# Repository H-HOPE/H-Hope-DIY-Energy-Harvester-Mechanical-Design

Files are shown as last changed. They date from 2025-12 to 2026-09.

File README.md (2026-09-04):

<div align="right">
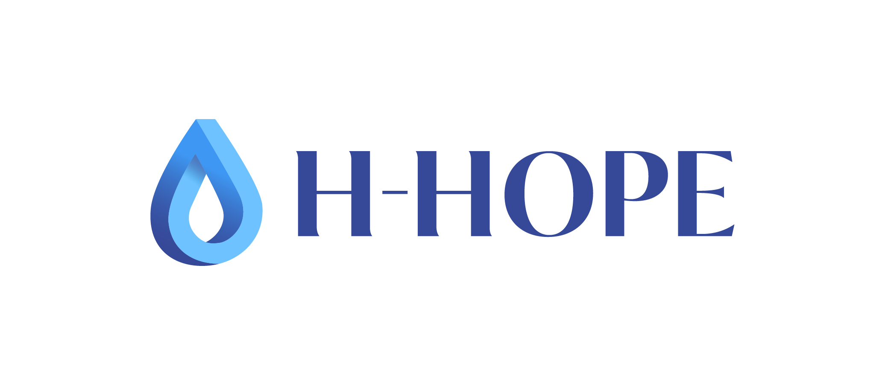
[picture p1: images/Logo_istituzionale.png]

</div>

# H-HOPE DIY Energy Harvester

**This guide is Part I of a three-part H-HOPE DIY build series.** Part I shows how to build the mechanical H-HOPE DIY energy harvester (the ‘harvester’) (the frame, oscillating cylinder, springs, transmission, flywheel and mechanical coupling) as either a **standalone demonstrator** or as a **complete mechanical module ready to connect to the H-HOPE DIY generator**. It contains everything a builder, student, or maker needs to go from parts to a working mechanical harvester:

---

**[Part II - H-HOPE DIY Generator](https://github.com/H-HOPE/H-HOPE-H-Hope-energy-harvester-induction-generator-design)** - Instructions for building the H-HOPE DIY generator that converts the harvester’s rotary/mechanical output into electrical power

**[Part III - H-HOPE DIY Electronics](https://github.com/H-HOPE/H-Hope-energy-harvester-electronic-design)** - Power control electronics that convert the H-HOPE DIY generator’s AC output into a USB-compatible DC supply for charging phones and small devices.

---

## Table of Contents

- [Introduction and principle of operation](#introduction-and-principle-of-operation)
- [Materials & Tools](#materials--tools)
  - [Bill of Materials & Price Estimate](#bill-of-materials--price-estimate)
  - [Tools](#tools)
- [3D Printed Parts for the harvester](#3d-printed-parts-for-the-harvester)
- [Harvester Assembly](#harvester-assembly)
  - [Aluminium frame and preloading mechanism (D and C)](#aluminium-frame-and-preloading-mechanism-d-and-c)
  - [Cylinder assembly (A)](#cylinder-assembly-a)
  - [Flywheel assembly (G)](#flywheel-assembly-g)
  - [Spring and rod assembly (B, E)](#spring-and-rod-assembly-b-e)
  - [Shaft (I)](#shaft-i)
    - [Shaft assembly With DIY Generator](#shaft-assembly-with-diy-generator)
    - [Without DIY Generator](#without-diy-generator)
  - [Assembly of the cylinder, springs and vertical rod to the Harvester frame](#assembly-of-the-cylinder-springs-and-vertical-rod-to-the-harvester-frame)
  - [Test of the operation](#test-of-the-operation)
- [Water-channel measurement results](#water-channel-measurement-results)
  - [Measurement parameters](#measurement-parameters)
    - [Cylinder size](#cylinder-size)
    - [Water velocity](#water-velocity)
    - [Oscillation amplitude](#oscillation-amplitude)
  - [Measurements results](#measurements-results)
    - [Best-performing configuration](#best-performing-configuration)
    - [Cylinder size comparison](#cylinder-size-comparison)
    - [Effect of water velocity](#effect-of-water-velocity)
  - [Practical build recommendation](#practical-build-recommendation)

---

## Introduction and principle of operation

The **harvester**, visible in Figure 1 is a simple, modular, and accessible mechanical system to convert the kinetic energy of flowing water into rotational motion, which is then converted into electrical power through a generator.  

The design is primarily aimed at **hobbyists, students, and researchers**, using standard aluminium profiles, off-the-shelf mechanical components, and basic workshop tools. All plastic components can be easily 3D-printed, with their models included in this build guide, while all remaining harvester parts are available on AliExpress for convenient sourcing.
The design emphasizes ease of assembly, allowing users to construct a fully functional water energy harvesting system without specialized machinery. By following step-by-step assembly instructions and using off-the-shelf parts, anyone can replicate the harvester to generate electricity from flowing water such as a small stream, river, channel, making it a practical and educational DIY project for sustainable energy exploration. For optimal performance, a water velocity between 0.6 and 1.0 m/s is recommended.

<p align="center">
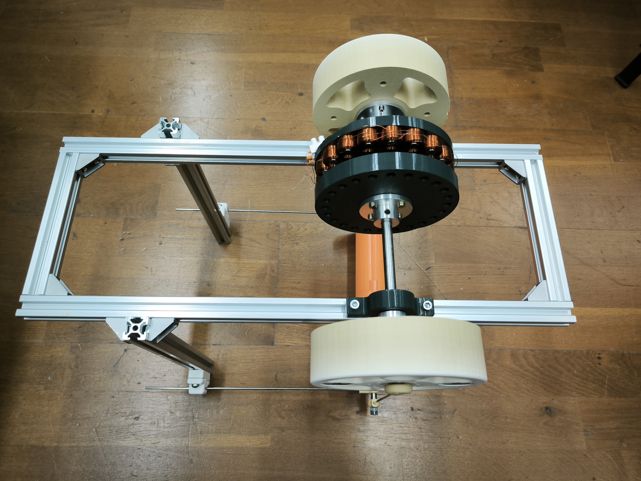
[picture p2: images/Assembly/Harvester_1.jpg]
  
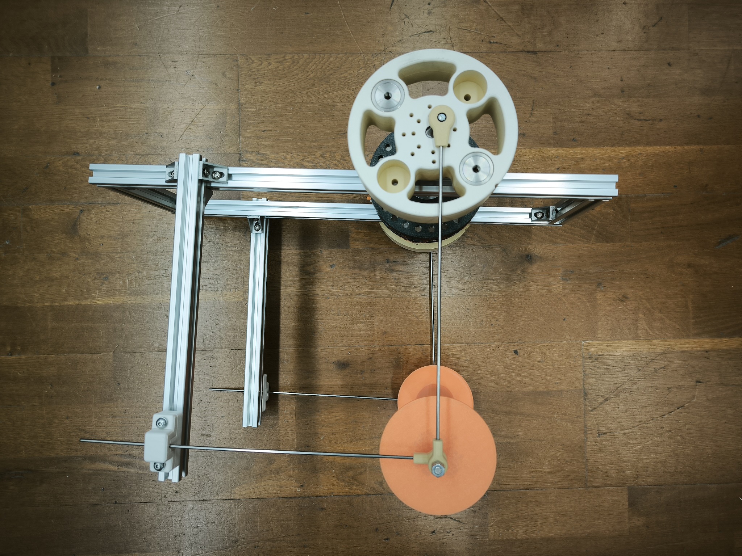
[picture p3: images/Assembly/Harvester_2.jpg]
  
</p>
<p align="center">
<b>Fig. 1:</b> Assembled harvester.</p>

<p align="center">
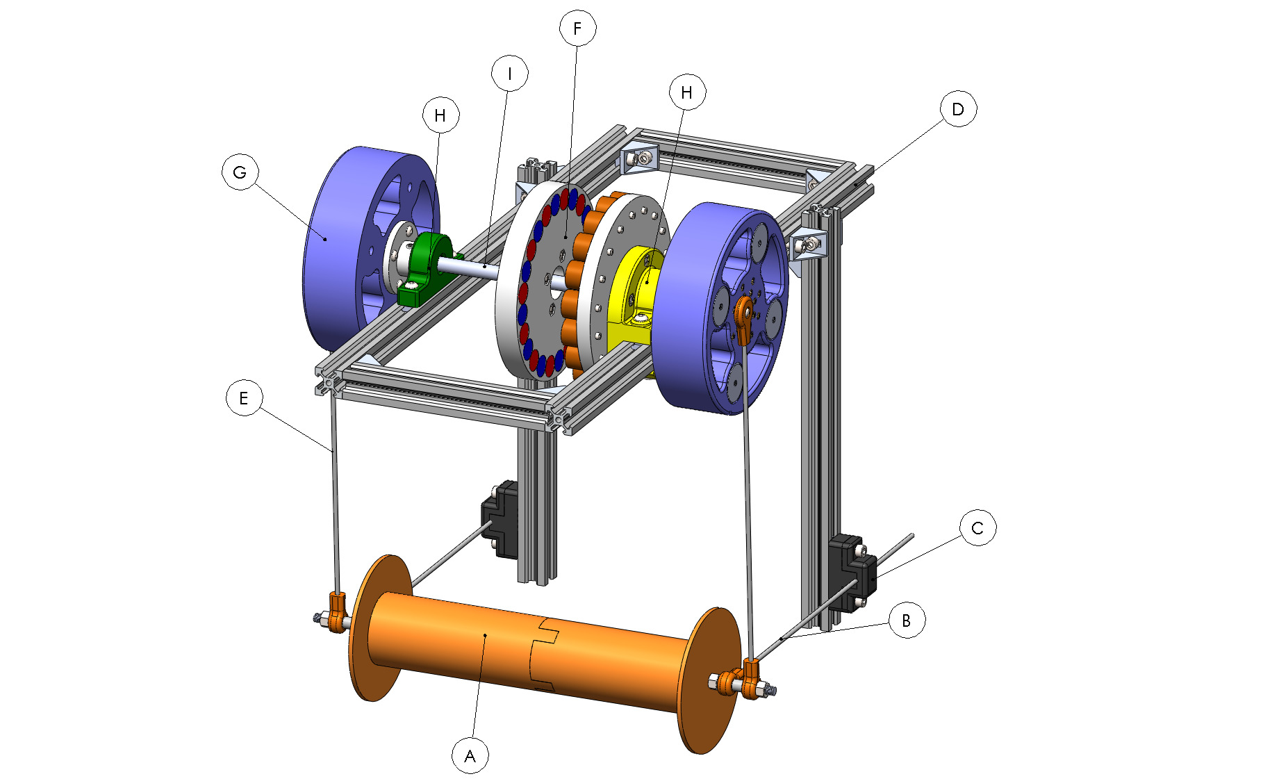
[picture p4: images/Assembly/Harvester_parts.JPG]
H-HOPE harvester
  
</p>

<p align="center"><b>Fig. 2:</b> View of the harvester model.</p>

The model of the harvester, visible in Figure 2 shows the mechanical structure of the harvester. The assembly consists of a modular aluminium frame supporting a horizontal oscillating cylinder, a flywheel, and vertical guide elements to transmit motion to a central shaft. In this configuration, the **cylinder (A)** is mounted horizontally and attached via **return springs (B)** to allow vertical oscillations while constraining horizontal movement. **Preloading mechanisms (C)** can adjust the spring tension to set the cylinder’s equilibrium position depending on its weight. **Vertical connecting rods (E)** with bearings transfer the oscillating motion of the cylinder to a **shaft (I)**,  which is supported by **bearings (H)**. This shaft is coupled to a **rotor (F)** and **flywheel (G)**, which help smooth the motion and can be linked to an induction generator. The **aluminium frame (D)** provides a modular and rigid support structure for the entire system. The pulley and cable arrangement visible in the image ensures the vertical movement of the cylinder is mechanically transmitted to the rotating shaft, which can then drive a generator rotor.

**Principle of Operation - Vortex-Induced Vibration (VIV)**

The vortex shedding process results in quasi-periodic pressure fluctuations around the cylinder. These alternating pressure differentials between the upper and lower surfaces generate an unsteady lift force, acting primarily in the transverse (vertical) direction. When the cylinder is mounted to permit vertical motion while restricting horizontal displacement, this oscillatory lift force induces vertical vibrations of the structure. The magnitude of the lift force is important for both performance and design of the VIV energy harvesters. For a given pressure differential, the lift force is proportional to the surface area exposed to the flow. Thus, increasing the cylinder diameter increases the area subject to pressure fluctuations, resulting in a higher lift force during vortex shedding. Where channel or stream dimensions allow, employing a cylinder with the maximum feasible height is advantageous, as it increases oscillation amplitude and improves the energy extraction potential and overall efficiency of the harvester.

Vertical harvester motion forms the basis for energy extraction in systems designed to harness vortex-induced vibrations (VIV), where mechanical oscillation energy is converted into usable electrical power. When the vortex shedding frequency approaches the natural frequency of the structure, resonance may occur, producing large-amplitude oscillations. Devices designed to extract energy from these oscillations are referred to as VIV energy harvesters, such as the system developed here. The harvester’s operating principle is based on Kármán vortex shedding coupled with large-amplitude oscillations of the energy harvester.

To harvest the lift force generated by the oscillating flow, the structure must allow large oscillatory displacements that can be sustained over time. Consequently, the natural (resonant) frequency of the harvester should be tuned to match, or lie very close to, the dominant vortex-shedding frequency of the flow, thereby maximising the energy captured per cycle.

---

## Materials & Tools

All the parts can be sourced from [AliExpress](https://www.aliexpress.com) using the links below. Some items (e.g., profiles or nuts) may also be available locally for faster delivery. Below is a complete list of all the components and hardware required for the build, including direct links and backup snapshots to AliExpress.

### Bill of Materials & Price Estimate

#### Frame
- 2x Bosch profile 500 mm ↘︎
- 2x Bosch profile 150 mm → [AliExpress items](https://www.aliexpress.com/item/1005002652962344.html) [Page screenshot](./images/1_profiles.PNG)
- 2x Bosch profile 300 mm ↗
- 20× Corner Bracket – joins → [AliExpress item](https://www.aliexpress.com/item/1005008248063572.html) [Page screenshot](./images/2_brackets.PNG)

#### Bearings
- 2× 10×26×8 mm (6000 OPEN) → [AliExpress item](https://www.aliexpress.com/item/1000006697893.html) [Page screenshot](./images/3_bearings_big.PNG)
  *(Open type has slightly less friction than closed)*  
- 2× 3×10×4 mm → [AliExpress item](https://www.aliexpress.com/item/1005007624995531.html) [Page screenshot](./images/3_bearings_small.PNG)

#### Flange
- 2× 10 mm inner diameter → [AliExpress item](https://www.aliexpress.com/item/1005006166768847.html) [Page screenshot](./images/4_flange.PNG)

#### Weights
- 4× (8×) 100 g weights → [AliExpress item](https://www.aliexpress.com/item/1005009254304005.html) [Page screenshot](./images/5_weights.PNG)

#### Inserts
- 50× M3 inserts (OD 4.5 mm, length 8 mm) → [AliExpress item](https://www.aliexpress.com/item/1005009169647177.html) [Page screenshot](./images/6_inserts.PNG)

#### Threaded Rod
- 1× M6, 500 mm → [AliExpress item](https://www.aliexpress.com/item/1005010030305641.html) [Page screenshot](./images/7_threaded_rod.PNG)

#### Shaft
- 1× 300 mm, Ø10 mm rod → [AliExpress item](https://www.aliexpress.com/item/1005007648254828.html) [Page screenshot](./images/12_main_rod.PNG)

#### Spacers
- 10× OD8 × M6 spacers, length 8 mm → [AliExpress item](https://www.aliexpress.com/item/1005009939446609.html) [Page screenshot](./images/8_spacer.PNG)

#### Stainless Steel Round Rod
- 4× 300 mm, Ø3 mm rods → [AliExpress item](https://www.aliexpress.com/item/1005006331386855.html) [Page screenshot](./images/9_round_rod.PNG)

#### Bolts, Nuts & Washers
- 10pcs M3 bolts, 12 mm in lenght → [AliExpress item](https://www.aliexpress.com/item/4001072025844.html) [Page screenshot](./images/10__M3_screws.PNG)

- 6pcs M6 nuts → [AliExpress item](https://www.aliexpress.com/item/1005006982532067.html) [Page screenshot](./images/11_M6_nuts.PNG)

- 4PCS M5 nuts and bolts 25 mm in lenght (for mounting the generator)
  
**Total Estimated Cost for the material (2025)** *(Generator and electronics not included)*

**≈ 95 €**

---

### Tools
- Screwdrivers, wrenches
- Drill/driver, bench vise
- Metal saw
- Vice
- 3D printer
- Safety gear (gloves, goggles)
- Quick glue
- Soldering iron (for inserting inserts)

---
## 3D Printed Parts for the harvester

A total of 17 parts need to be 3D-printed to complete the harvester assembly. All parts are available in both STL and STEP formats and can be downloaded here: [3D printed harvester parts](./3D%20parts). For added protection against moisture or water exposure, you can optionally coat the printed parts with a plastic spray sealant. The printing process of the parts is visible in Figure 3.

<p align="center">
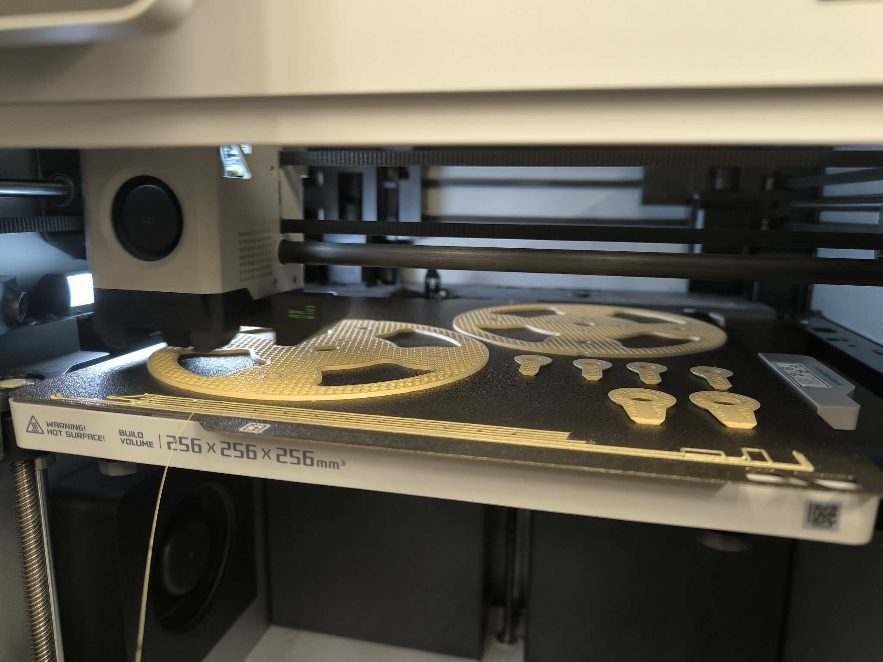
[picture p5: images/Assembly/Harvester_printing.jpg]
H-HOPE harvester
  
</p>

<p align="center"><b>Fig. 3:</b> Printing the 3D parts for the harvester.</p>

---

## Harvester Assembly

 - The **harvester** may be assembled either **with the H-HOPE DIY generator** attached, as visible in Figure 4 left **or as a standalone mechanical module**, as visible in Figure 4 right. When built without the generator the unit can function as a mechanical demonstrator and can be left ready for later coupling to a third-party generator.

 - Build instructions and parts lists for both configurations (Mechanical only and Mechanical and Generator) are provided below so the builder can choose the configuration that best fits their goals.

<p align="center">
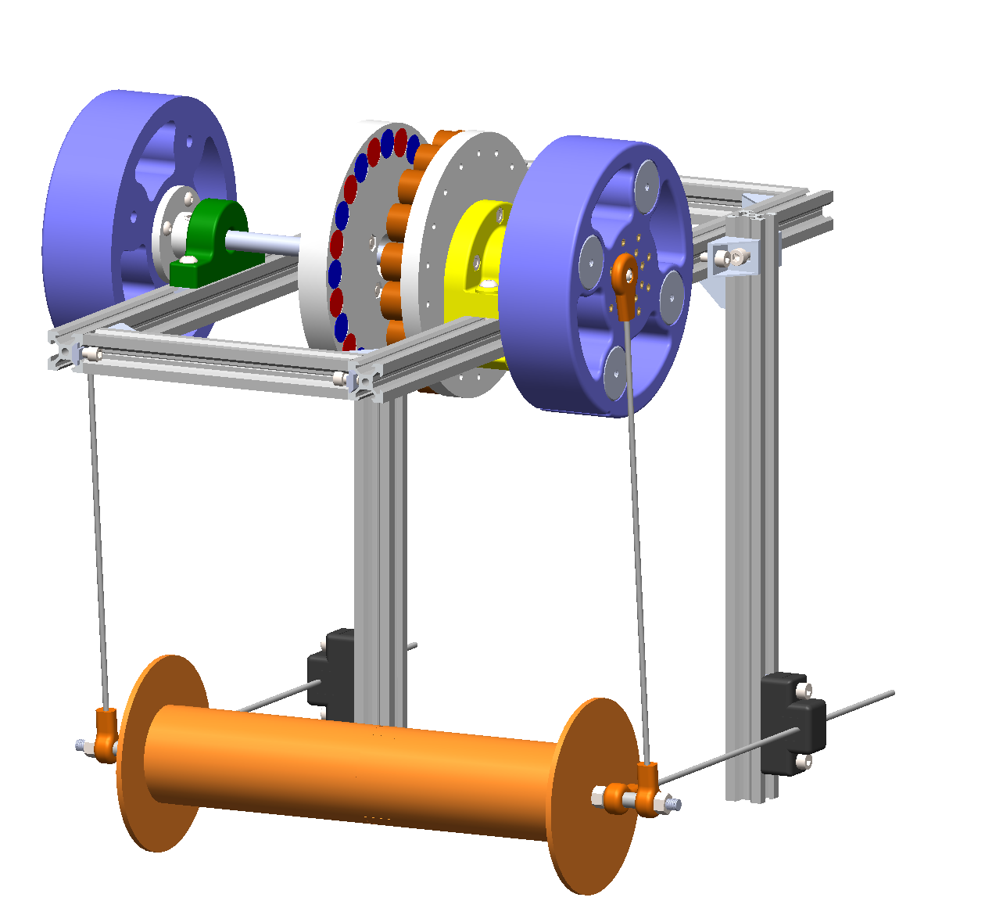
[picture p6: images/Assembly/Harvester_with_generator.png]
  
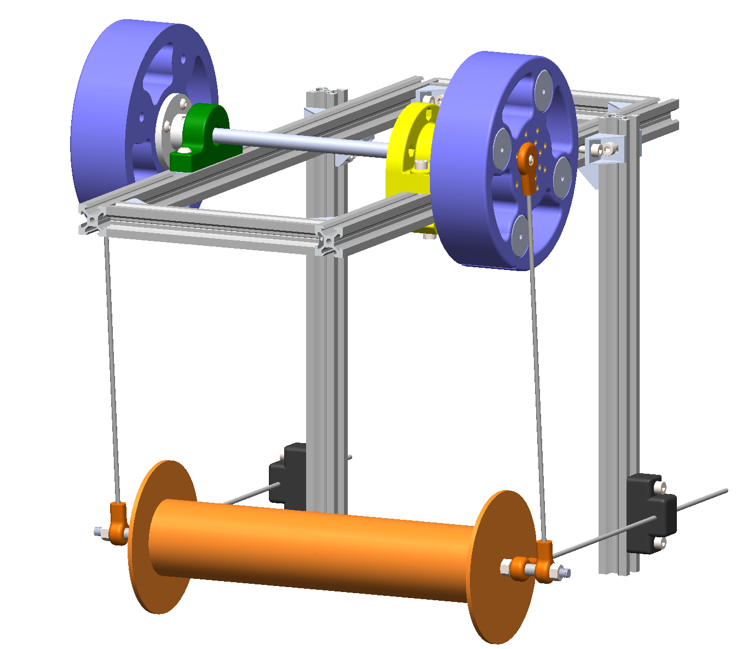
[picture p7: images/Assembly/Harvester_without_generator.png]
  
</p>
<p align="center">
<b>Fig. 4:</b>Harvester assembly with (left) and without (right) the H-HOPE DIY generator.
</p>

Figure 4 shows a model view of the harvester, with (left) and without (right) the H-HOPE DIY generator, displaying its individual mechanical components and how they are assembled.

The assembly process, regardless of the generator installation, is identical up to the "Shaft" section. This section is divided into two parts, allowing the user to follow the procedure either with or without the generator assembly.

### Aluminium frame and preloading mechanism (D and C)

The assembly of the harvester begins with the assembly of the aluminium frame (D) and preloading mechanism (C).

<p align="center">
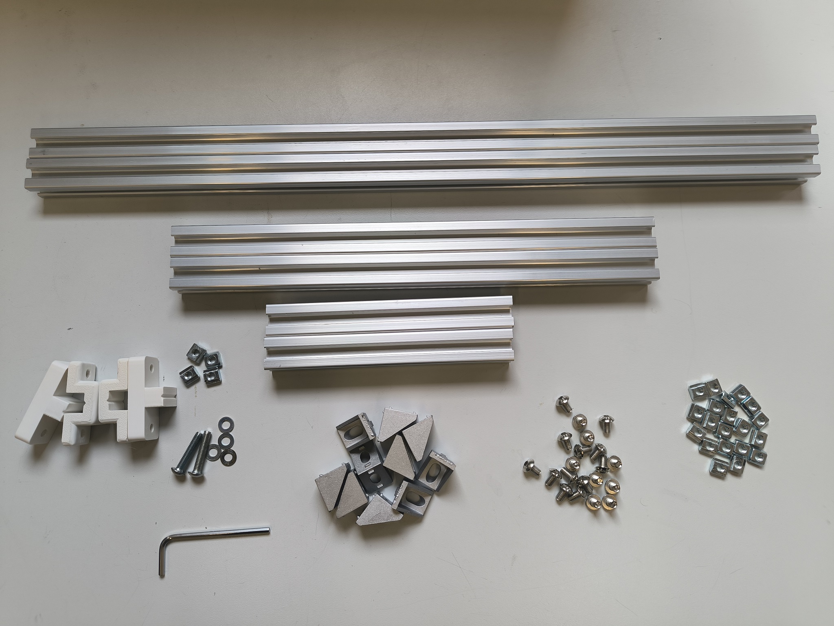
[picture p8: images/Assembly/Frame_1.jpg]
  
</p>
<p align="center">
<b>Fig. 5:</b> Harvester frame and preloading mechanism assembly parts.
</p>

First assemble the **horizontal part of the aluminium frame (D)** with corner brackets and M6 fasteners. Place two 500 mm, 20x20 mm Aluminium profiles in parallel. Add two 150 mm profiles at each end, to connect the 500mm profiles together. Assemble the profiles together with joints at each of the 4 corners, as visible in the animation on the right side of Figure 6. The finished harvester horizontal profile is visible in Figure 7.

<p align="center">
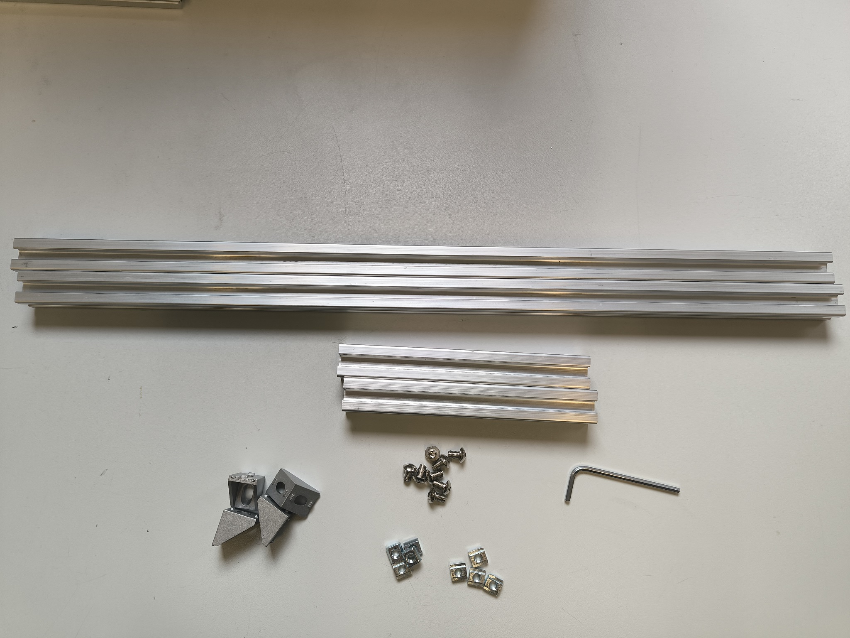
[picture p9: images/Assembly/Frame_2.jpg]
  
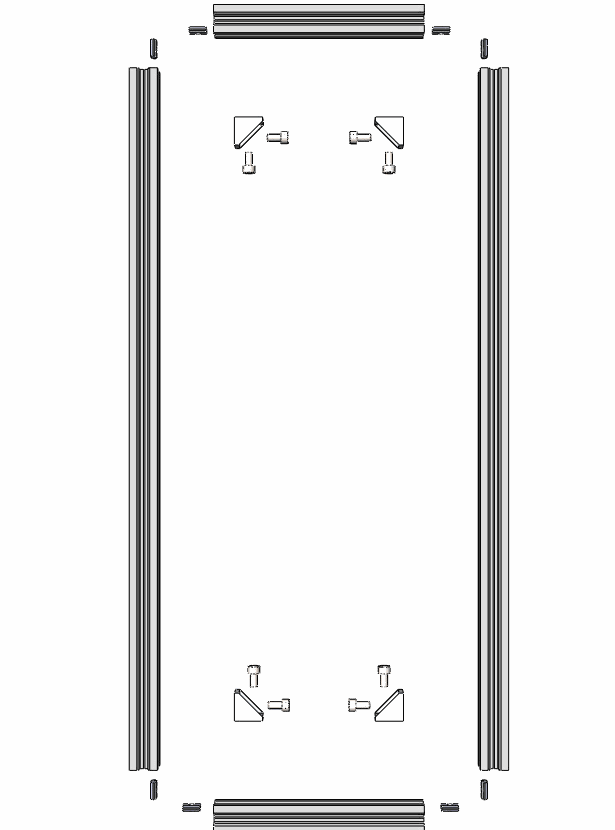
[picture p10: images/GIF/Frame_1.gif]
  
</p>
<p align="center">
<b>Fig. 6:</b> Harvester horizontal frame assembly parts (left) and animation of harvester horizontal frame assembly (right).
</p>

<p align="center">
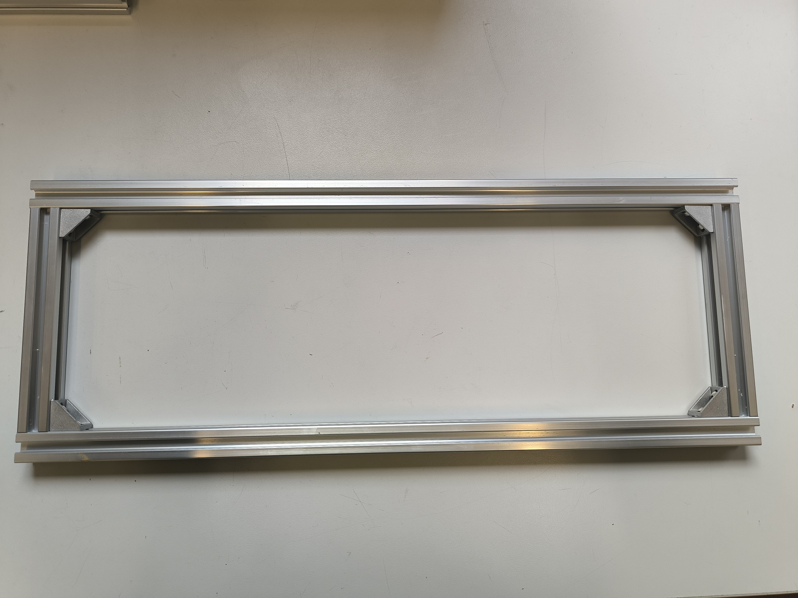
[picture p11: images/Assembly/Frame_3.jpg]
  
</p>
<p align="center">
<b>Fig. 7:</b> Completed harvester horizontal frame assembly.
</p>

**Assembly of the harvester vertical aluminium frame and preloading mechanism**.

First, install the preloading mechanism components (shown in Figure 8 and in the animation in Figure 9) onto the vertical 300 mm, 20x20 mm aluminium profiles. The required length of the four M5 bolts is 23 mm, however, in this assembly, 25 mm bolts were used along with two additional washers to achieve the correct overall length.

<p align="center">
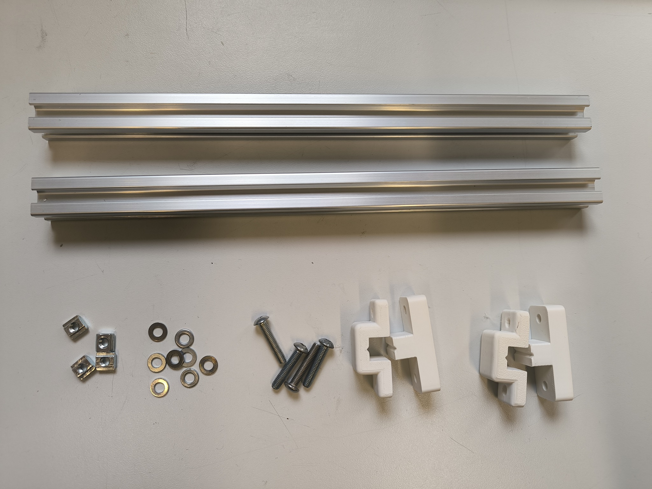
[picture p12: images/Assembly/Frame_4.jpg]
  
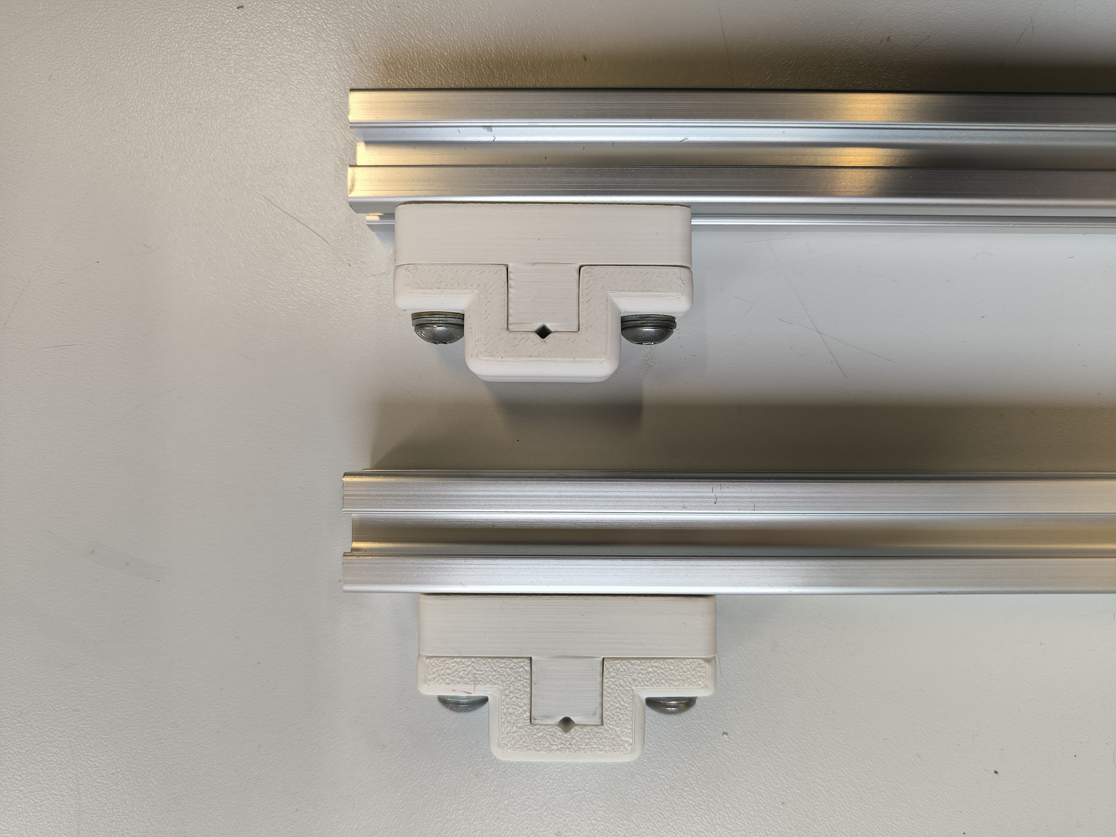
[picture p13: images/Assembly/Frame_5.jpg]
  
</p>
<p align="center">
<b>Fig. 8:</b> Harvester preloading mechanism parts (left) and finished assembly of the preloading mechanism (right).
</p>

<p align="center">
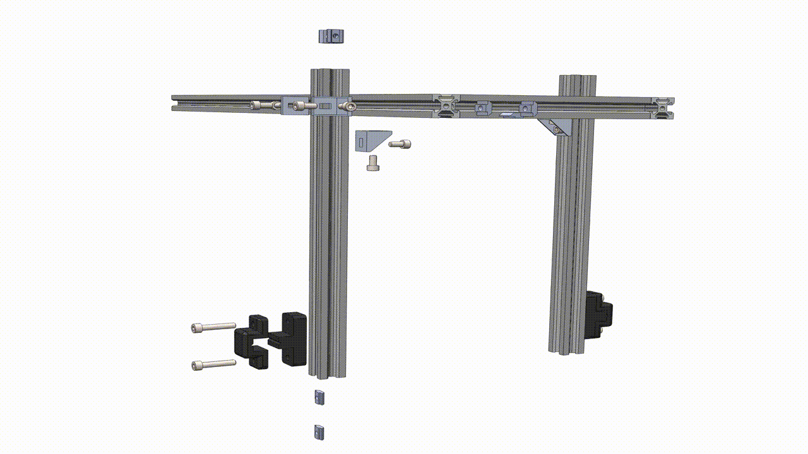
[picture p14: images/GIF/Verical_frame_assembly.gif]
  
</p>
<p align="center">
<b>Fig. 9:</b> Animation of harvester horizontal frame and preloading mechanism assembly.
</p>

Place each 300 mm profile vertically and secure it with three joints to the harvester horizontal profile, one at the bottom, one on the left side, and one on the right side, then repeat the same process on the opposite side of the frame, ensure that each profile extends 8 mm above the top of the frame and that the bottom part of the preloading mechanism is positioned 15 mm from the lower end of the vertical profile, as illustrated in the left side of the Figure 11. Ensure **profile alignment** to minimize bearing wear and losses.

Before connecting vertical profiles to the horizontal aluminium frame, sand off the excessive aluminium pins (if they exist) in corner joints to make a good connection, as visible in Figure 10 (left and right).

<p align="center">
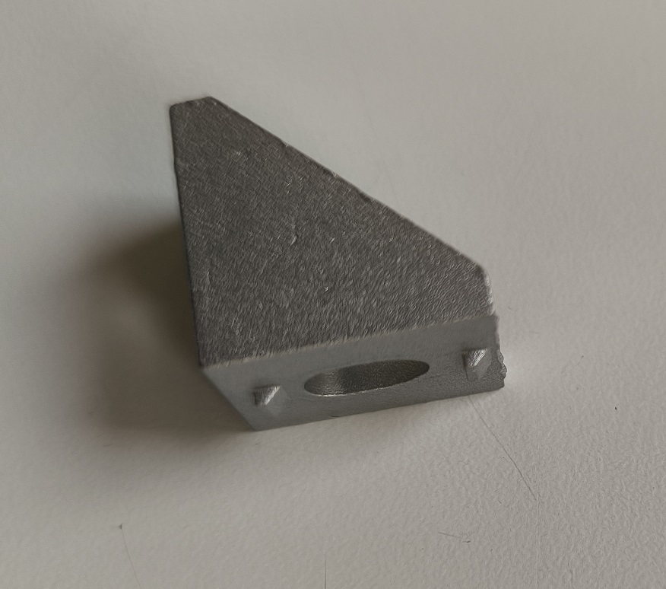
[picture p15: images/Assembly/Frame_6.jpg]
  
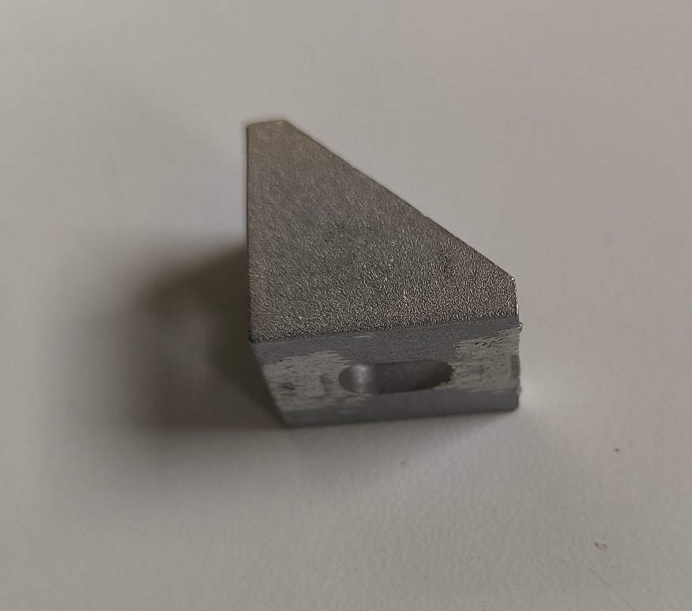
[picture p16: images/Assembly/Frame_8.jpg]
  
</p>
<p align="center">
<b>Fig. 10:</b> Sanded pins on aluminium joints.
</p>

<p align="center">
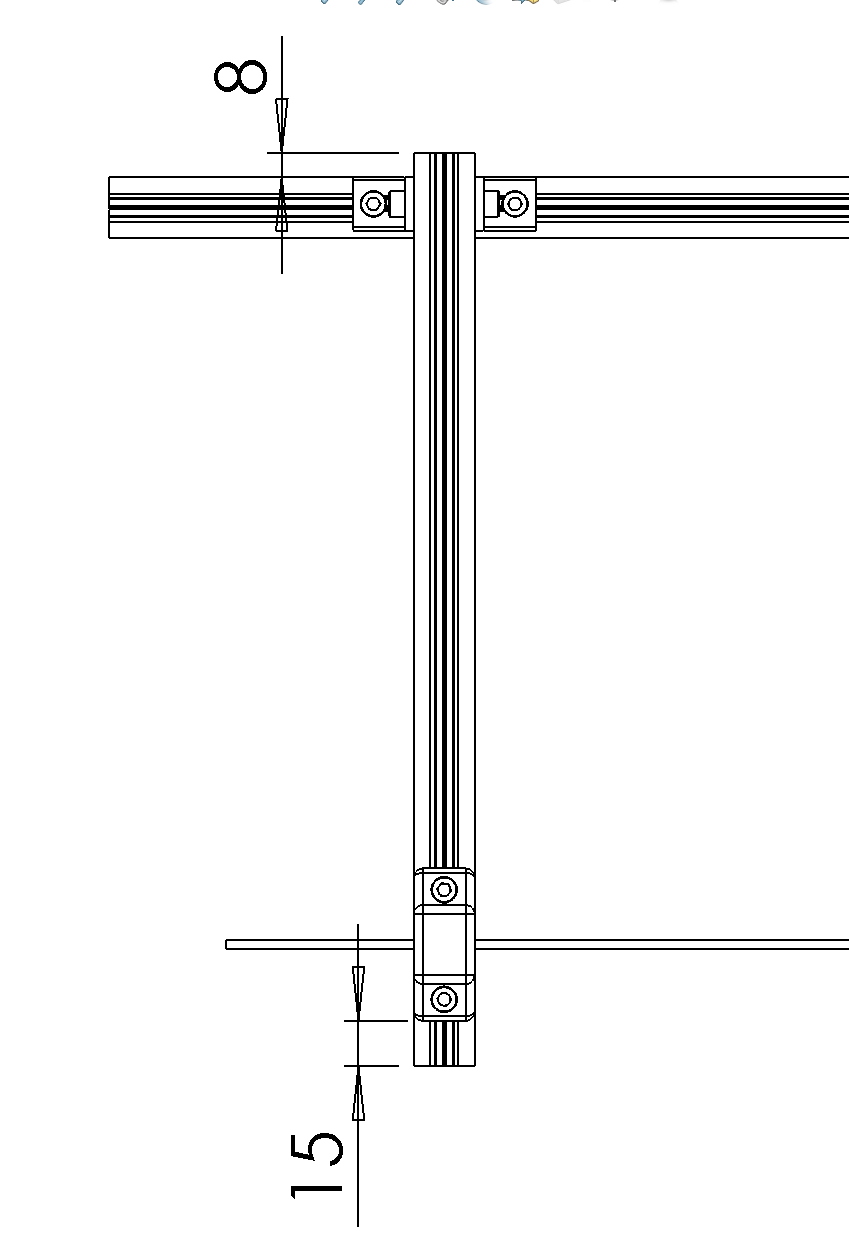
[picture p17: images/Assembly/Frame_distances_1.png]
  
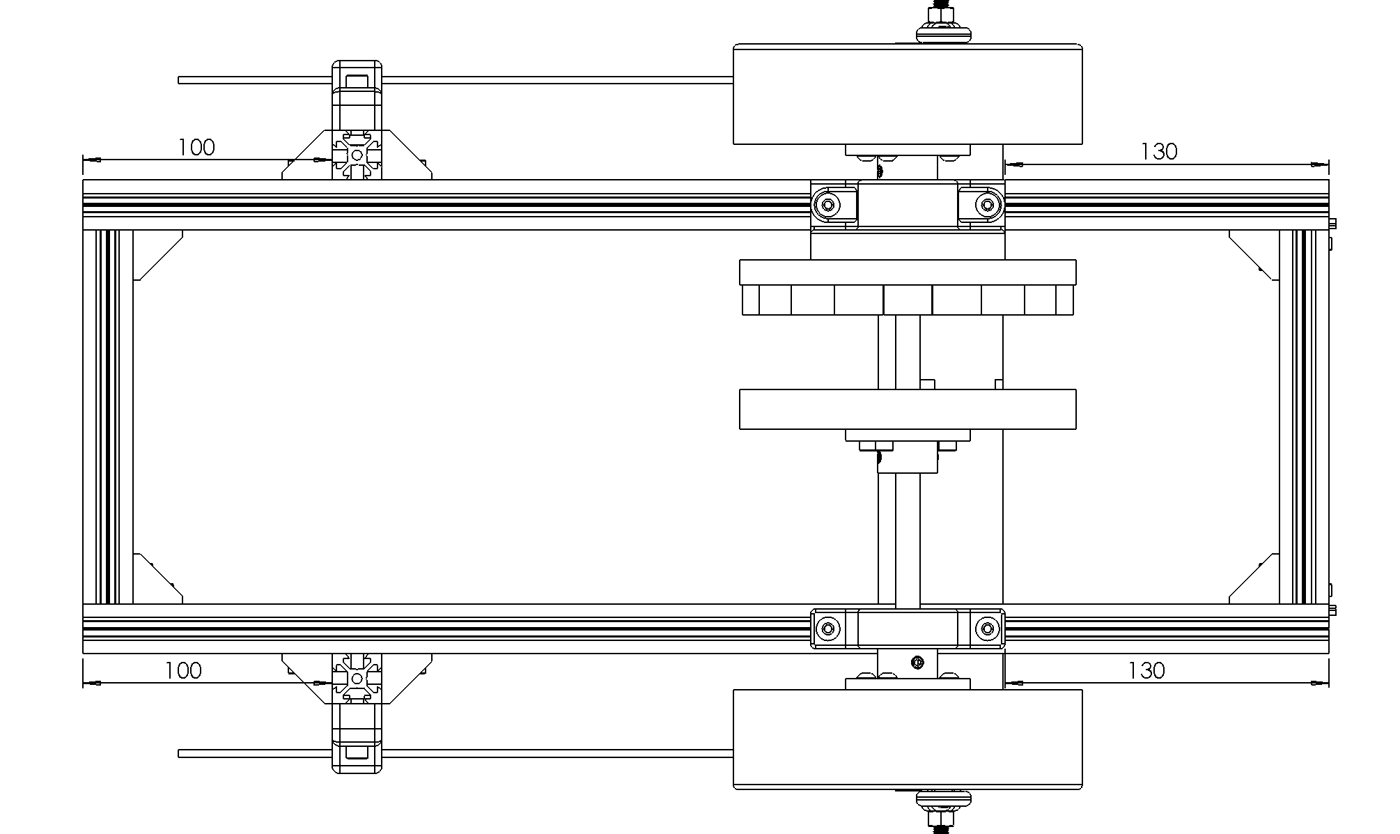
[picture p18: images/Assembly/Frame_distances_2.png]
  
</p>
<p align="center">
<b>Fig. 11:</b> Mounting offset of the preloading mechanism, vertical profiles (left) and offset of the items installed on the horizontal frame (right).
</p>

The finished frame assembly is shown in Figure 12.

<p align="center">
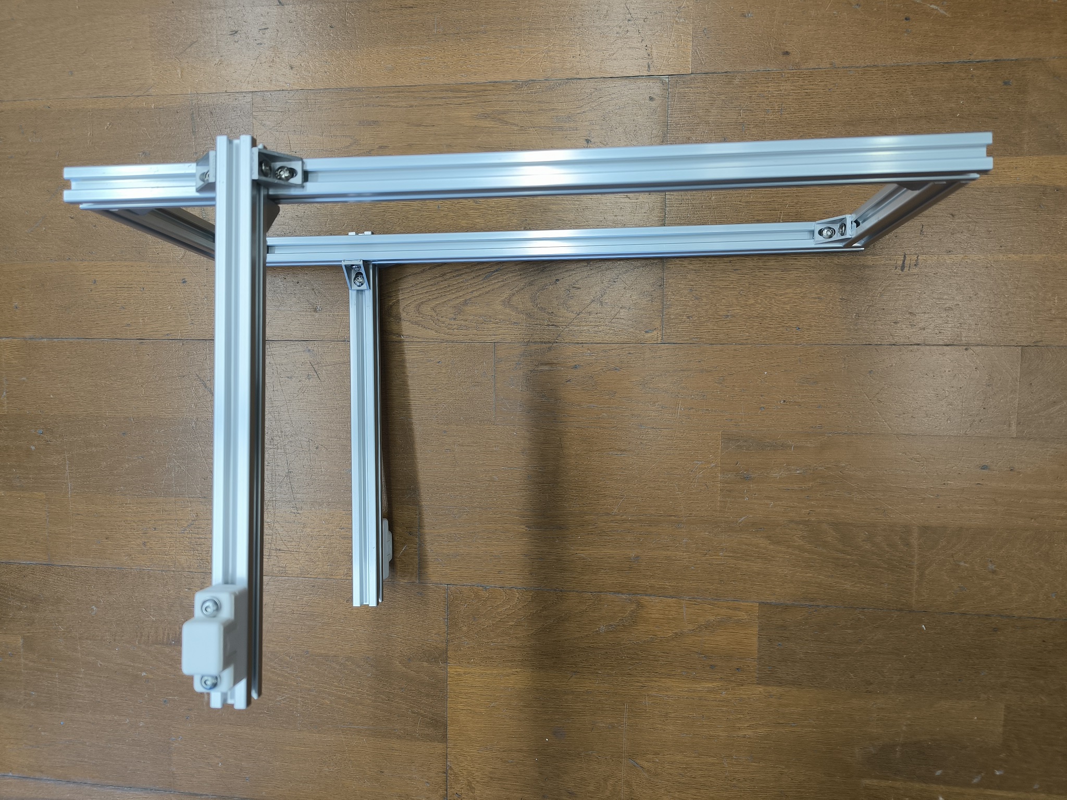
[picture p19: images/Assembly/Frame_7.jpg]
  
</p>

<p align="center"><b>Fig. 12:</b> Assembled harvester aluminium frame.</p>

---

### Cylinder assembly (A)

We continue with the harvester cylinder assembly (A).

In the left side of Figure 13 we can see the parts needed to assemble the harvester cylinder. We can see that the cylinder is 3D printed and is made from two parts. At each end of the cylinder there is a larger disc, that improves the harvester efficiency. The cylinder has a 6 mm hole running through its entire length. On the right side, there are six M6 nuts and two 6x8 mm spacers, below is a 500 mm M6 threaded rod.

<p align="center">
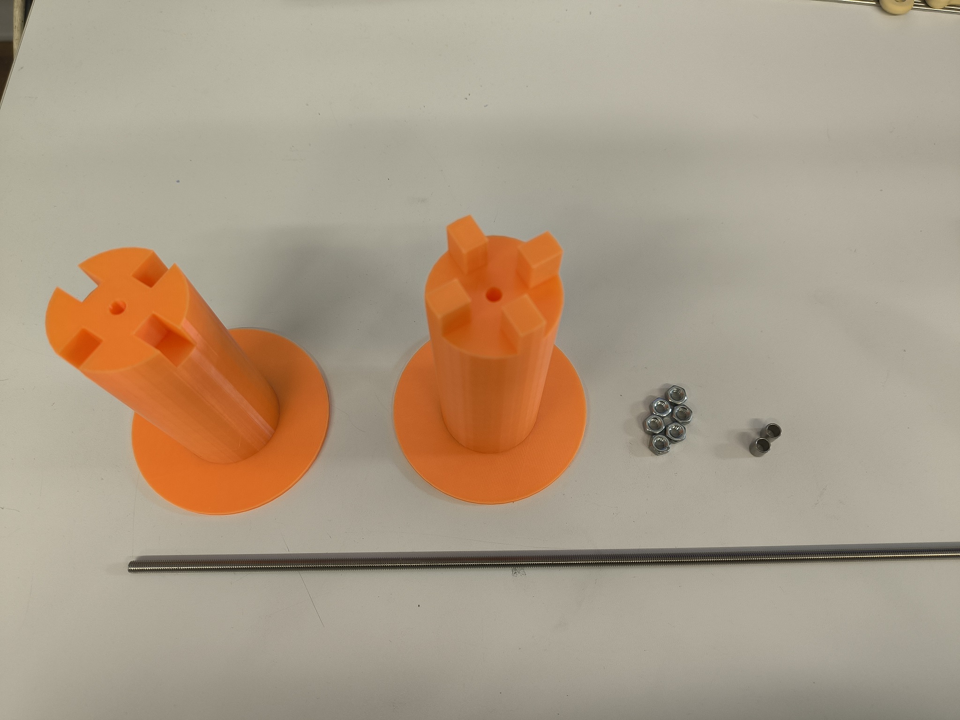
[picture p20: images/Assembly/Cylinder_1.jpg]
  
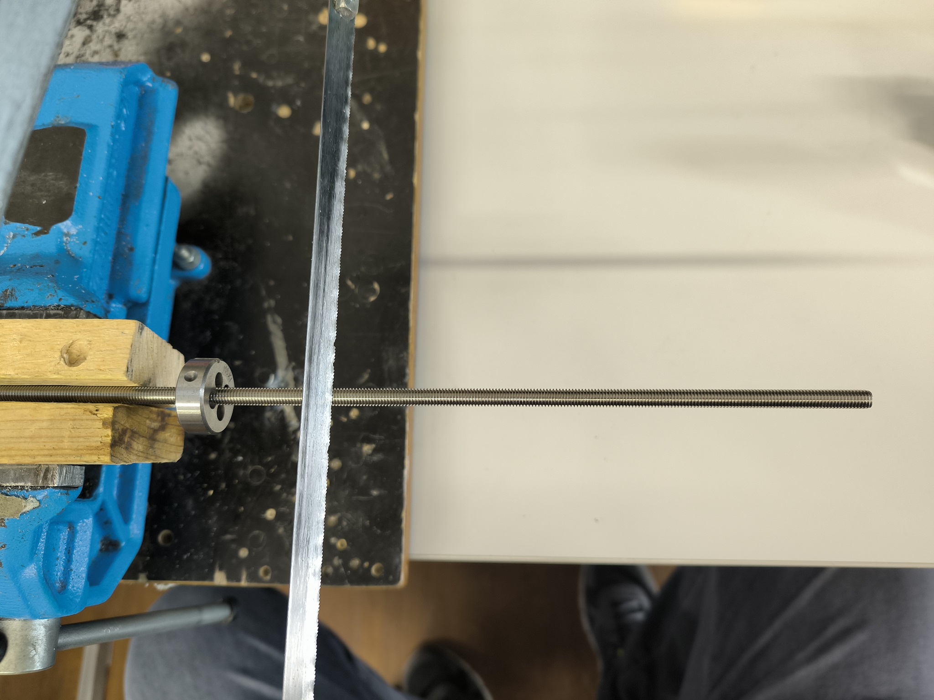
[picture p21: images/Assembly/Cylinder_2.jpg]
  
</p>
<p align="center">
<b>Fig. 13:</b> Cylinder assembly parts (left) and rod cutting (right).
</p>

<p align="center">
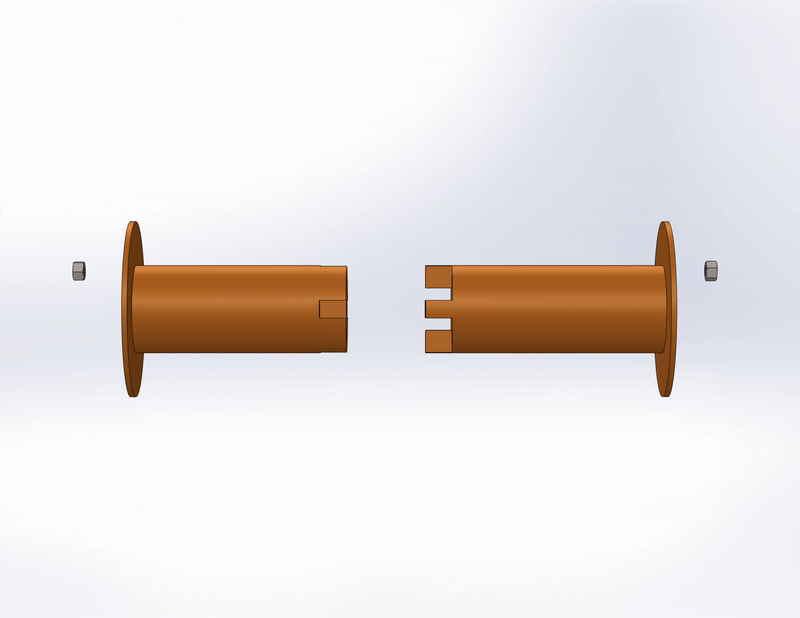
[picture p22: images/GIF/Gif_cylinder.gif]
  
</p>
<p align="center"><b>Fig. 14:</b> Animation of harvester cylinder assembly.</p>

The first step is to shorten the M6 rod by 165 mm to 335 mm, as visible in Figure 13 (right). After that, assemble the cylinder and install the threaded rod through the cylinder hole. At each end of the rod add two M6 nuts and lightly tighten them. To each side add a spacer and additional 2 M6 nuts, as visible in the animation on Figure 14 and Figure 15.

<p align="center">
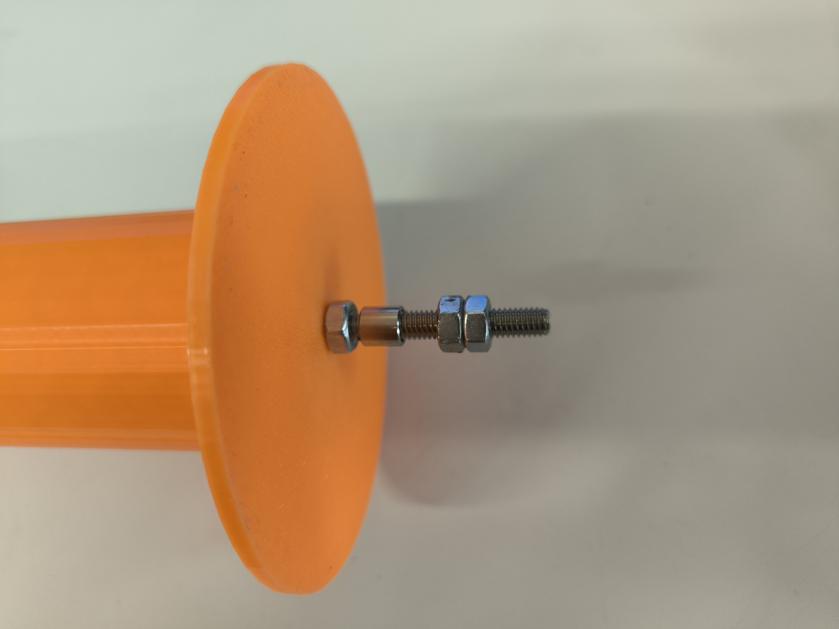
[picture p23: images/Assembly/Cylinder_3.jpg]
  
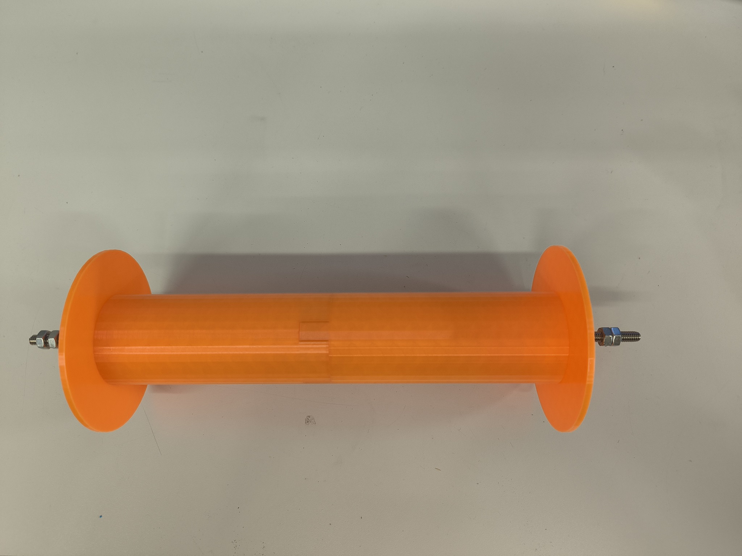
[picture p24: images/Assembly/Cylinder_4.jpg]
  
</p>
<p align="center">
<b>Fig. 15:</b> Installed nuts and spacer, left and assembled cylinder, visible on the right.
</p>

### Flywheel assembly (G)

The next step is to assemble the harvester flywheel (G).

<p align="center">
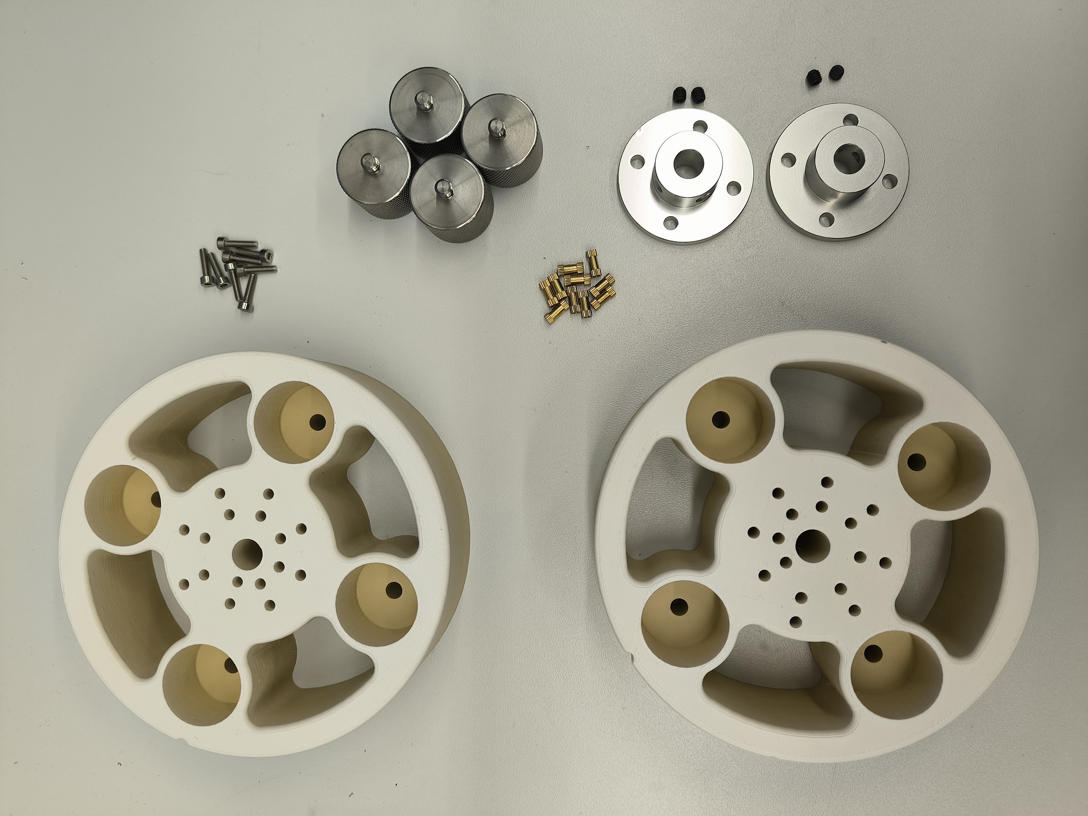
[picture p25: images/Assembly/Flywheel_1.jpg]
  
</p>

<p align="center"><b>Fig. 16:</b> Flywheel assembly parts.</p>

<p align="center">
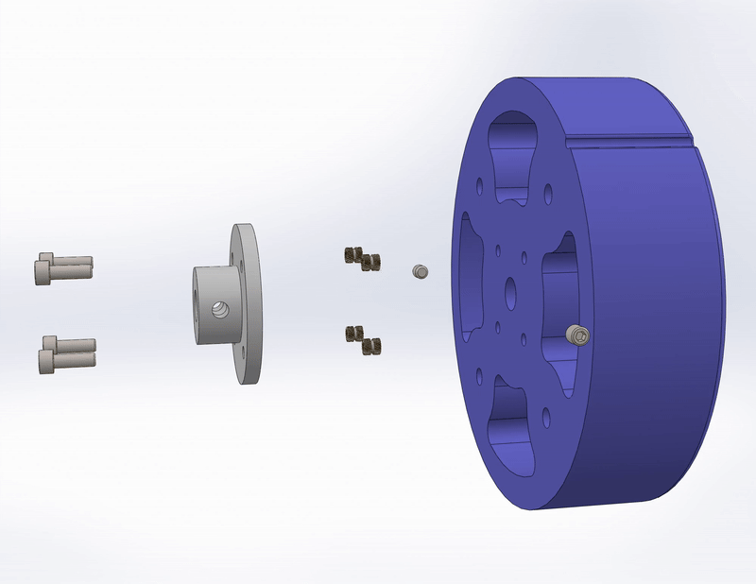
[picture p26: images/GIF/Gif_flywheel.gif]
  
</p>
<p align="center"><b>Fig. 17:</b> Animation of harvester flywheel assembly</p>

With the help of a soldering iron insert four M3 inserts into the holes in the back side of the flywheel, as visible in Figure 18.

<p align="center">
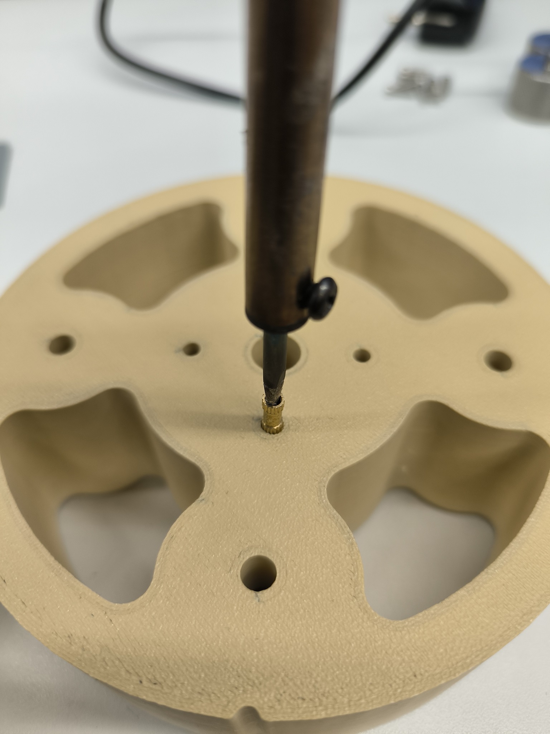
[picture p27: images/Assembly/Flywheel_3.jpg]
  
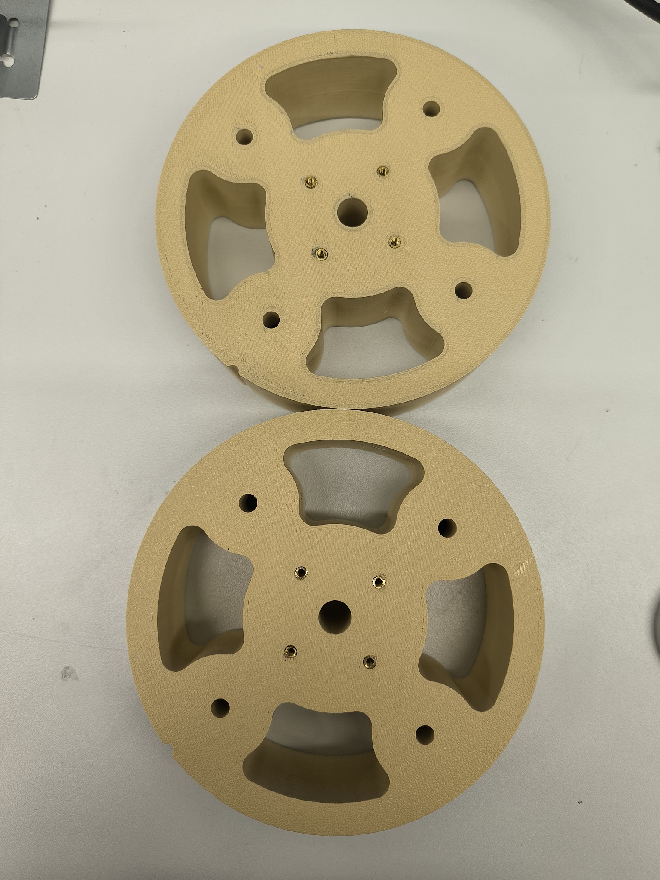
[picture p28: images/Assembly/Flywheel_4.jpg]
  
</p>
<p align="center">
<b>Fig. 18:</b> Installing the M3 inserts with a soldering iron on the back side of a flywheel.
</p>

Install two inserts in the front end of a flywheel into the third hole, closest to the center, as visible in Figure 19.

<p align="center">
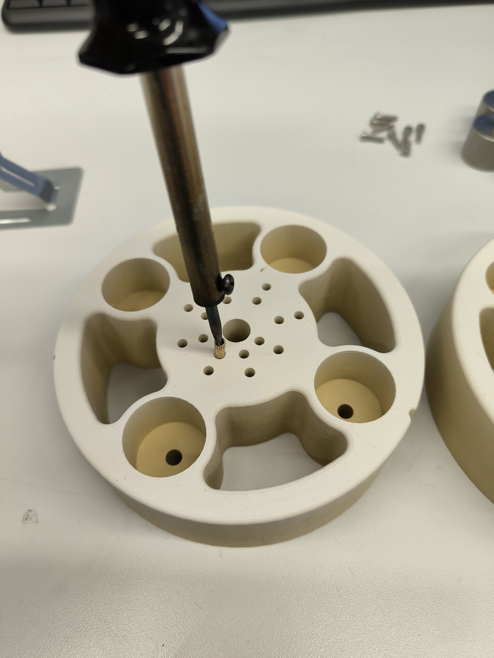
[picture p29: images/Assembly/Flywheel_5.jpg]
  
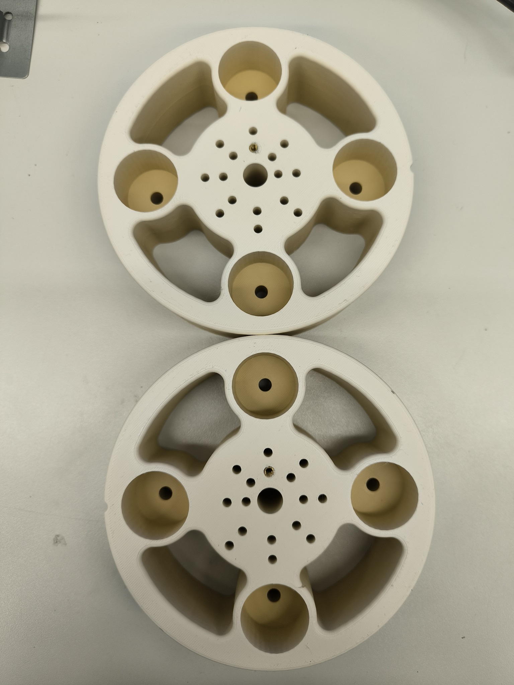
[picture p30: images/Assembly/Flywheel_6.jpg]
  
</p>
<p align="center">
<b>Fig. 19:</b> Installing the M3 insert with a soldering iron on the front side of a flywheel.
</p>

 Use M3 20 mm in length bolts, to fix the flange to the back side of a flywheel. The flange must be positioned as visible in Figure 20.

<p align="center">
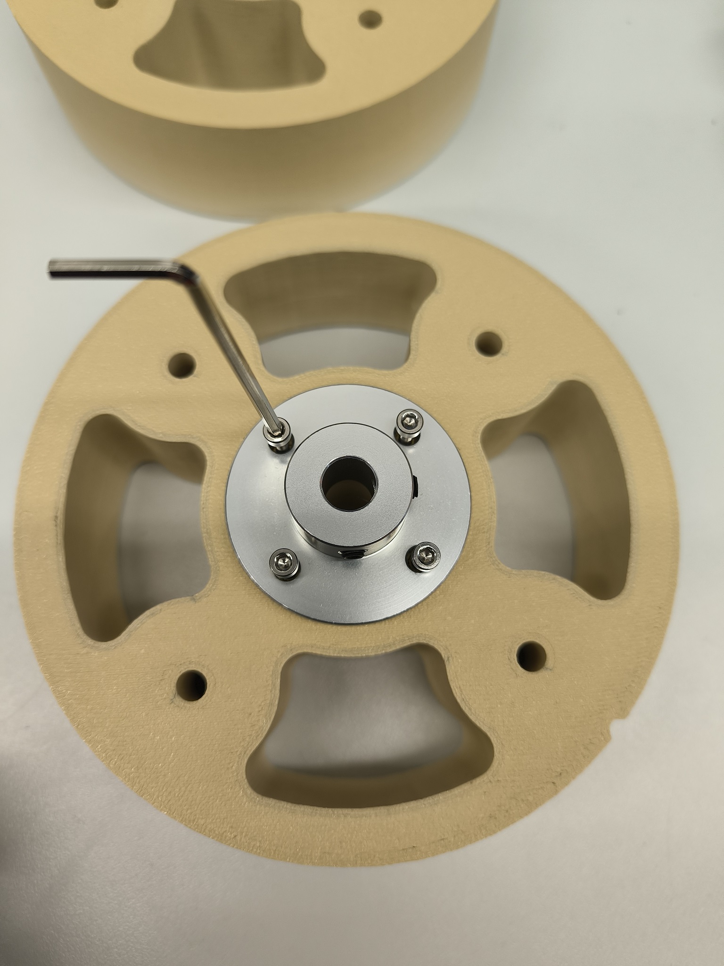
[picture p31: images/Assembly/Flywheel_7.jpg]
  
</p>
<p align="center">
<b>Fig. 20:</b> Installing the flange on the flywheel. 
</p>

Add two 100 g weights in opposite holes into each flywheel, as visible in the right side of a Figure 21.

<p align="center">
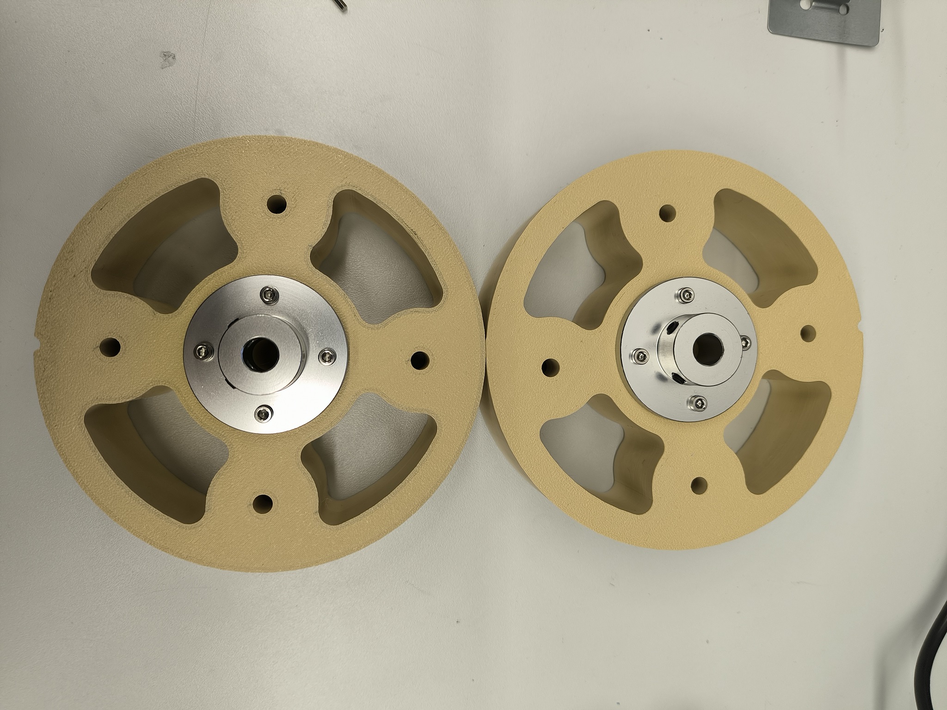
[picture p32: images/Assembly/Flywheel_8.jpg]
  
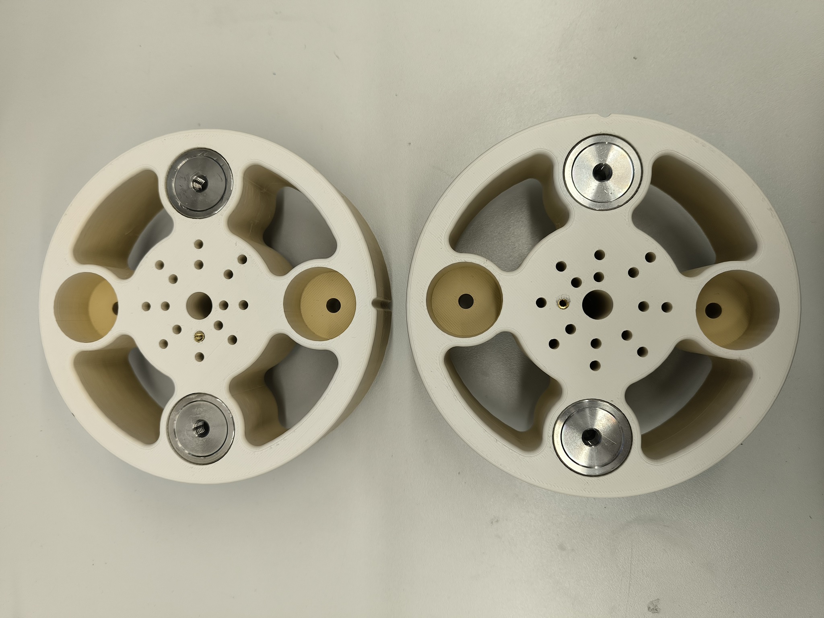
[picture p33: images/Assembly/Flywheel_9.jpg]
  
</p>
<p align="center">
<b>Fig. 21:</b> Flywheel with installed flanges on left and weights on the right.
</p>

### Spring and rod assembly  (B, E)

The harvester return spring (B) and vertical rod (E) are made from 3 mm stainless steel rod, two bearings, six printed parts and four spacers, as visible in Figure 22. The animation on how to assemble the vertical rod is visible in Figure 23.

<p align="center">
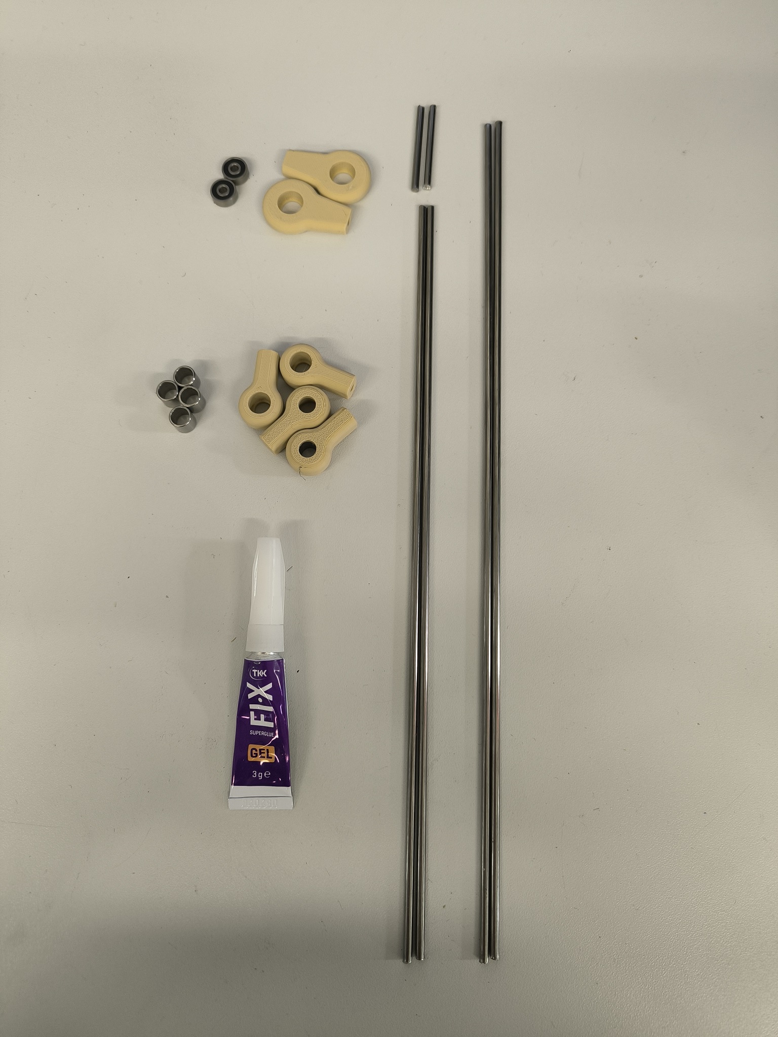
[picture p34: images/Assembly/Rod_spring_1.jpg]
  
</p>
<p align="center"><b>Fig. 22:</b> Parts required for assembly of the harvester return spring and vertical rod.</p>

<p align="center">
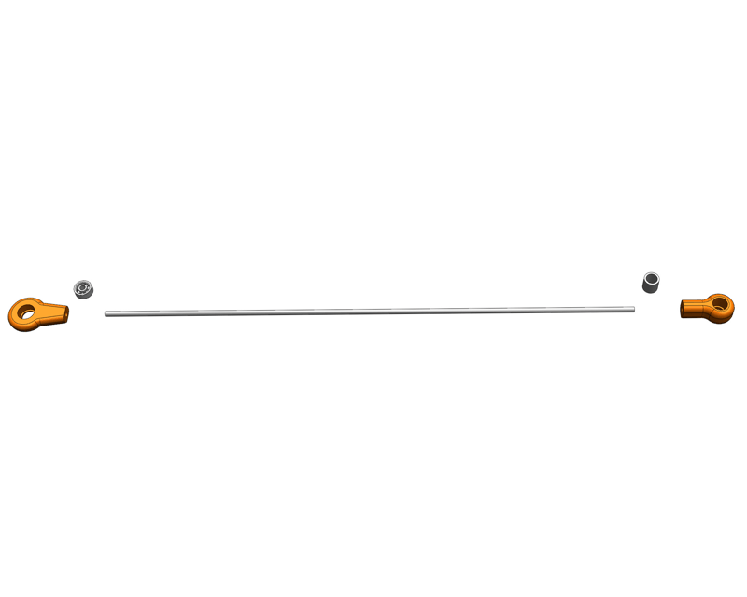
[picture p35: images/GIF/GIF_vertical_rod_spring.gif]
  
</p>
<p align="center"><b>Fig. 23:</b> Animation of the harvester vertical rod assembly.</p>

First, cut two of the 300 mm rods down by 35 mm to 265 mm; these will be used as the harvester’s vertical rods. Leave the other two rods at their full 300 mm length for the return spring.

Insert the two 3x10x4 mm bearings into the openings of the two 3D-printed end caps, as visible in the lower-left side of Figure 24. Insert the four spacers into the holes of the 3D-printed end caps, as shown on the upper-left side of Figure 24. Then attach the 3D-printed end caps to the ends of the vertical rods (E), and fit only two onto the return spring (B), as shown on the right side of Figure 24. It is recommended to apply a small amount of quick glue into the hole just before inserting the 3D printed plastic end caps to improve bonding.

<p align="center">
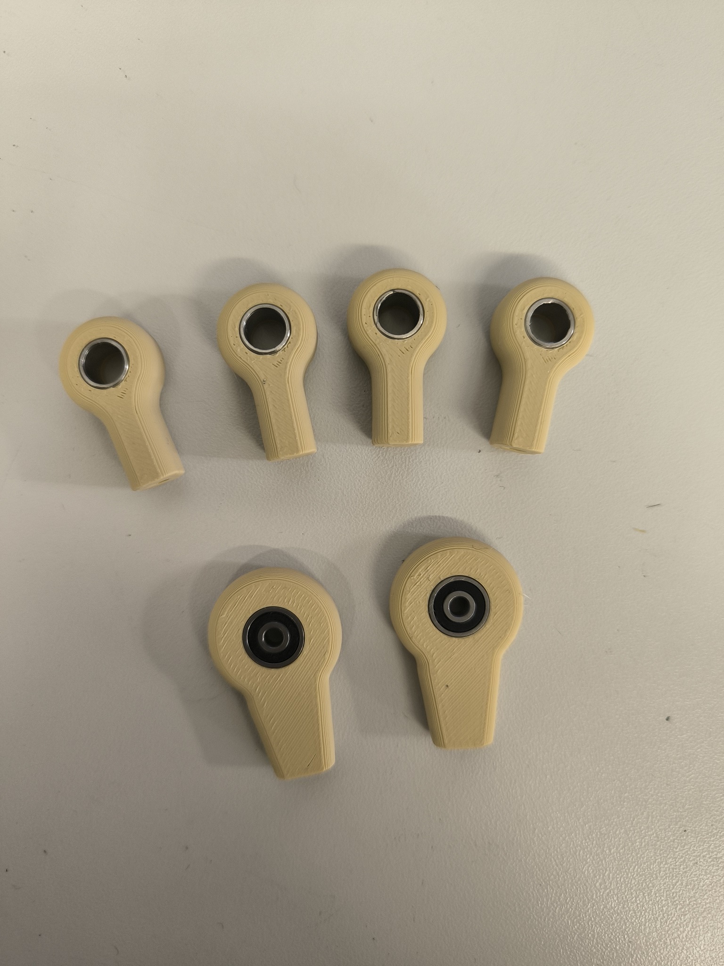
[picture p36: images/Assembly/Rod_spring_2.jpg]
  
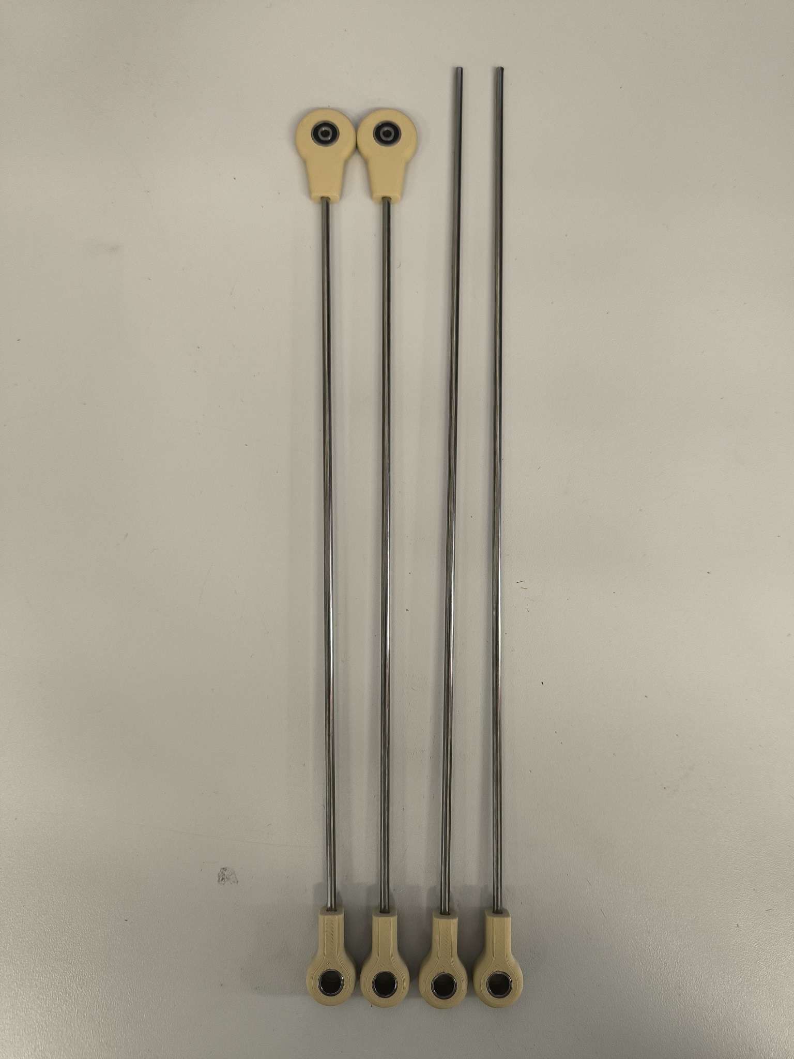
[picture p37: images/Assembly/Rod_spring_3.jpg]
  
</p>
<p align="center">
<b>Fig. 24:</b> 3D printed plastic endings with inserted bearings and spacers (left) and assembled return springs and vertical rods (right).
</p>

### Shaft (I)

The harvester shaft (I) carries both flywheels and, in the “with‑generator” configuration, the H‑HOPE DIY generator rotor. It converts the vertical oscillation of the cylinder into rotary motion and, when the generator is installed, also provides the mechanical input to the electrical part of the system.

The shaft assembly is based on a 300 mm long, Ø10 mm steel rod, two 6000‑type bearings, two 3D‑printed bearing holders, two flywheels (G) and, optionally, the H‑HOPE DIY generator rotor and stator. All the parts, needed for shaft assembly are visible in Figure 25.

#### Shaft assembly With DIY Generator
<p align="center">
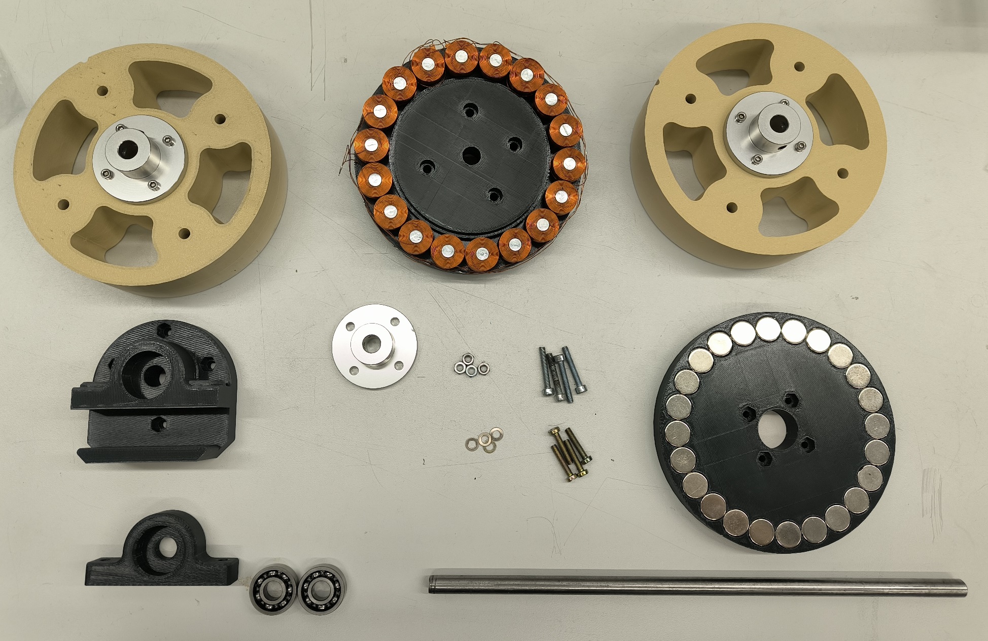
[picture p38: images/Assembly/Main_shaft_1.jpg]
  
</p>
<p align="center"><b>Fig. 25:</b> Parts required for assembly of the harvester shaft - with H-HOPE DIY generator.</p>

<p align="center">
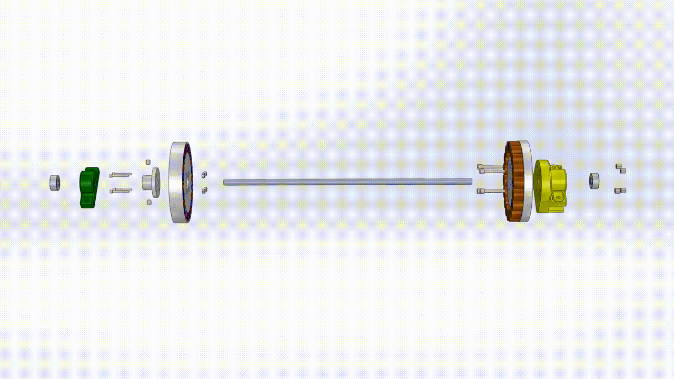
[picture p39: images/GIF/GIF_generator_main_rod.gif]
  
</p>
<p align="center"><b>Fig. 26:</b> Animation of the main shaft assembly with integrated H‑HOPE DIY generator.</p>

First, press one 10×26×8 mm bearing into each 3D‑printed bearing holder (Figure 27, left). Make sure the bearings are fully seated and square to the plastic surface.

<p align="center">
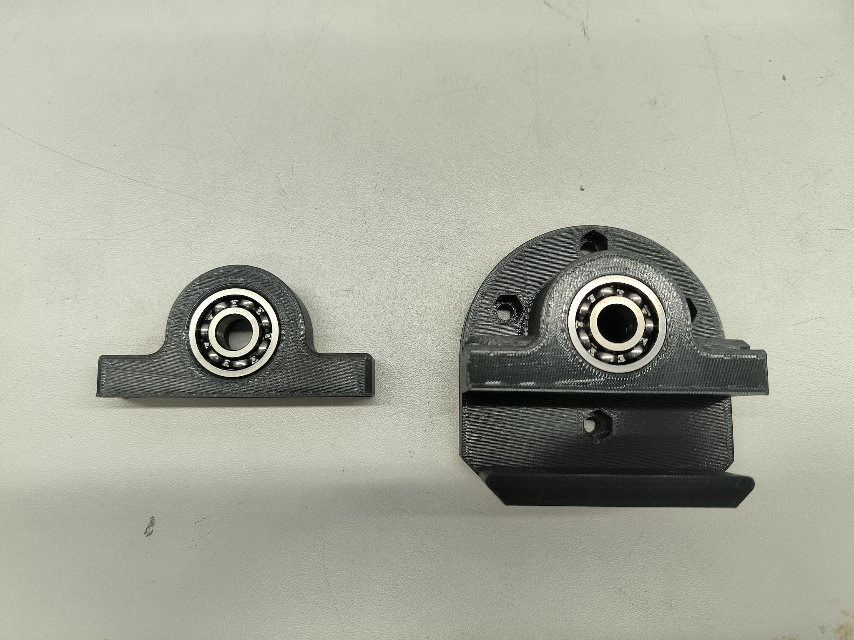
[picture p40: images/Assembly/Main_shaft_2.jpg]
  
  Right view
</p>
<p align="center">
<b>Fig. 27:</b> 3D‑printed bearing holders with bearings inserted (left) and generator stator mounted to the larger bearing holder (right).
</p>

Next, prepare the bearing holder that will carry the generator stator.

Insert four M5 nuts into the hexagonal pockets of the larger bearing holder. Place the generator stator so that the phase output block points outward and the coil side faces the future rotor position. Fix the stator to the bearing holder using four M5 bolts, as shown in Figures 27 (right) and 28 (left). Tighten the bolts evenly so that the stator sits flat on the mounting surface.

<p align="center">
  Left view
  Right view
</p>
<p align="center">
<b>Fig. 28:</b> DIY H-HOPE generator stator attached to the bearing holder, image from front side (left), DIY H-HOPE generator rotor attached to the flange (right).
</p>

Prepare the generator rotor as follows: Mount the aluminium shaft flange to the centre of the rotor disc using three M3 bolts (Figure 28, right). Ensure that the flange is centred and that the bolts are securely tightened. If not already done in Part II of the guide, glue the magnets into the circular pockets of the rotor disc, alternating polarity as required by the generator design.

<p align="center">
  Left view
  Right view
</p>
<p align="center">
<b>Fig. 29:</b> Completed rotor with glued magnets (left) and overview of the assembled generator components, flywheels, one bearing block and shaft (right).
</p>

Now you can assemble the shaft. Slide the generator rotor (with flange and magnets) onto the 10 mm shaft and tighten the flange clamping bolts so the rotor is roughly centred along the rod. Slide the stator–bearing‑holder assembly onto the shaft from the opposite side. At this stage the stator is not yet fixed to the frame, so you can freely adjust the air‑gap between rotor and stator (typically 4-6 mm). Add the second bearing holder onto the shaft on the other side of the rotor. Finally, mount one flywheel onto each end of the shaft and tighten their hub bolts against the shaft flat (or directly onto the shaft if no flat is present).

<p align="center">
  Left view
</p>
<p align="center">
<b>Fig. 30:</b> Fully assembled main shaft with flywheels at both ends, rotor fixed to the shaft and stator attached to its bearing holder.
</p>

At this point the complete “shaft module” is assembled, but not yet installed on the aluminium frame. Before mounting it, check that the shaft can be rotated by hand and that both bearings run smoothly.  

Figure 31 shows the finished shaft module (left) and an example of its final position in the frame (right). In the right photo a tape measure can be used to set the horizontal position of the bearing holder from the start of the aluminium profile. 

<p align="center">
  Left view
  Right view
</p>
<p align="center">
<b>Fig. 31:</b> Completed shaft assembly, ready for mounting on the harvester (left) and example of the recommended horizontal positioning of the bearing housing on the horizontal aluminium frame (right).
</p>

To install the shaft assembly into the harvester frame place the frame on a flat surface and attach the smaller bearing housing to one horizontal aluminium profile and the stator bearing housing to the opposite horizontal profile using T‑nuts and M5/M6 bolts, as shown in Fig. 31 (right). Adjust the position of both bearing holders using a ruler or tape measure so they are at the same distance from the edge of the horizontal frame. Lightly tighten the bolts, rotate the shaft and fine‑tune the position of both bearing blocks until the shaft spins freely without binding, then fully tighten the bolts.

#### Without DIY Generator

The assembly process is the same, simply omit mounting the H-HOPE generator stator to the 3D-printed bearing and generator holder, and do not mount the generator rotor on the rod.

### Assembly of the cylinder, springs and vertical rod to the Harvester frame.

In this step the three main mechanical sub‑assemblies are connected:
- the **oscillating cylinder** with its threaded M6 rod,
- the **return springs and vertical rods**, and
- the **shaft module** with flywheels and (optionally) generator.

<p align="center">
  Left view
  Right view
</p>
<p align="center">
<b>Fig. 32:</b> Cylinder, spring–rod assemblies and shaft module before installation (left) and attachment of the springs to the pre‑loading mechanisms (right).
</p>

**Attach the springs to the frame.**
Hook one end of each spring onto the upper hook of the pre‑loading mechanism on both sides of the frame (Figure 32, right). Leave the lower ends of the springs free for now; they will later connect to the cylinder.

**Install the cylinder between the springs.**
Place the cylinder in the centre of the frame, with the M6 threaded rod running horizontally. Attach the lower spring hooks to the 3D‑printed eyelets on the cylinder ends. At this stage the cylinder should be suspended by the two springs and able to move vertically with very little friction.

<p align="center">
  Left view
  Right view
</p>
<p align="center">
<b>Fig. 33:</b> Connection of the vertical rods to the cylinder (left) and hardware required to fix the upper ends of the rods to the flywheels (right).
</p>

**Connect the vertical rods to the cylinder.**
- Slide the lower bearings of the vertical rods onto the protruding M6 threaded rod on each side of the cylinder.
- Fix them in place using M6 nuts and, if required, spacers so that the rods remain vertical and parallel to the frame (Figure 33, left).
- Check that the rods can pivot freely on their bearings without binding.

**Adjust spring pre‑load.**
Rotate the pre‑loading bolts to set the desired spring tension. The cylinder should rest approximately in the middle of its travel when the springs are unloaded (no water flow). You can fine‑tune this later during testing.

**Connect the vertical rods to the flywheels.**
- Rotate the shaft so that the attachment holes in both flywheels are aligned and approximately above the vertical rods.
- Using the hardware shown in Figure 33 (right), bolt the upper bearings of the vertical rods to the flywheel connection points. Make sure that both rods are attached at the same radius from the shaft centre to guarantee symmetric motion.

<p align="center">
  Left view

</p>
<p align="center">
<b>Fig. 34:</b> Bolt and spacer view, before connecting the vertical rod to the flywheel. The same procedure is repeated on the opposite side.
</p>

Once both rods are connected, slowly move the cylinder up and down by hand. The flywheels should start to rotate smoothly and the cylinder should return to its equilibrium position when released. If you notice any sticking or misalignment:

- Check that the vertical rods are straight and parallel.
- Verify that the spring forces are balanced left/right.
- Loosen the bearing block bolts slightly and re‑align the shaft until the rotation is smooth.

When these checks are complete, the full mechanical harvester assembly is finished and you can proceed to the Test of the operation section.

### Test of the operation

The H-HOPE energy harvester was tested in a water channel at a constant flow velocity of 0.9 m/s. The water depth during the test was 25 cm. Figures 35 and 36 show the harvester in operation. A video of the harvester with the  [DIY H-HOPE generator](https://github.com/H-HOPE/H-HOPE-H-Hope-energy-harvester-induction-generator-design) and [power electronics](https://github.com/H-HOPE/H-Hope-energy-harvester-electronic-design) is also available on YouTube [here](https://youtu.be/Jox99EthLKE).

<p align="center">
  H-HOPE harvester
</p>
<p align="center"><b>Fig. 35:</b> Animation of the H-HOPE energy harvester in operation during water-channel testing at a flow velocity of 0.9 m/s (water depth 25 cm).</p>

<p align="center">
  Left view
  Right view
</p>
<p align="center">
<b>Fig. 36:</b> H-HOPE energy harvester in operation during water-channel testing at a flow velocity of 0.9 m/s (water depth 25 cm).
</p>

## Water-channel measurement results

To evaluate the performance of the energy harvester, a series of experimental tests was carried out with different combinations of test parameters. The main test parameters were the cylinder diameter, water velocity, and oscillation amplitude. These parameters were varied to investigate their influence on the oscillatory response of the cylinder and the resulting mechanical power transfer to the generator.

Three cylinder sizes were tested under different flow conditions and prescribed oscillation amplitudes. For each test configuration, the oscillation frequency and generator torque were measured while the electrical load was gradually increased. This testing procedure allowed us to evaluate how individual parameters affect the operation and performance of the energy harvester.

A sample video of the test measurements is available here: https://youtu.be/U6G2Xj3FoK8

### Measurement parameters

#### Cylinder size

Three 3D-printed cylinders (A), with diameters of 50 (blue), 60 (black), and 70 mm (red), as shown in Figure 37, were tested. All cylinders had a length of 0.25 m. The relative density and mass of each cylinder can be seen in the table below.

| Cylinder diameter | Relative density | Mass |
|---:|---:|---:|
| 50 mm | 0.690 | 0.366 kg |
| 60 mm | 0.524 | 0.400 kg |
| 70 mm | 0.446 | 0.463 kg |

<p align="center">
  H-HOPE harvester
</p>
<p align="center"><b>Fig. 37: </b>3D-printed cylinders, with diameters of 50 (blue), 60 (black), and 70 mm (red)</p>

The return springs (B) were made from 3 mm stainless-steel rod and had a free length of 350 mm. The water channel was 500 mm wide and 500 mm high, as visible in Figure 35 and 36. 

#### Water velocity

The following combinations of water velocity and water depth in the water channel were tested:

| Water velocity | Water depth |
|---:|---:|
| 0.70 m/s | 210 mm |
| 0.80 m/s | 210 mm |
| 0.90 m/s | 210 mm |
| 1.10 m/s | 180 mm |
| 1.20 m/s | 200 mm |

#### Oscilation amplitude

Cylinder displacement is expressed as **oscillation amplitude**. The oscillation amplitude is set by the position where the vertical connecting rod (E) is attached to the flywheel (G) as visible in Figure 19. Moving the attachment point closer to or further from the shaft (I) changes the vertical travel of the cylinder. Therefore, the amplitude is a fixed mechanical setting for each test and does not change freely with water velocity.

Oscillation amplitudes of 20, 30 and 40 mm were tested (Figure 38). During each test, the oscillation frequency and torque on the generator stator were measured at different electrical loads. The electrical load was increased until the maximum torque at which the cylinder could still oscillate.

<p align="center">
  H-HOPE harvester
</p>
<p align="center"><b>Fig. 38: </b>Mouting points for oscillation amplitudes of 20, 30 and 40 mm are indicated by black arrows.</p>

### Measurements results

#### Best-performing configuration

The **60 mm cylinder gave the best overall results** during the water-channel measurements.

**The highest measured efficiency was obtained with the 60 mm cylinder at a water velocity of 0.80 m/s and an oscillation amplitude of 30 or 40 mm. The efficiency was slightly above 8.5%**.

When the results from the different amplitudes were compared, the 60 mm cylinder also had the highest average oscillation frequency, generated power and efficiency.

The difference of power output and efficiency between the **30 and 40 mm** amplitudes was relatively small. For general operation, an oscillation amplitude between 30 and 40 mm is recommended.

If the primary objective is to maximize generated power rather than efficiency, the highest measured value was achieved at a water velocity of 1.20 m/s using the 60 mm cylinder and an amplitude of 40 mm, resulting in a generated power of **0.46 W**. Although the higher water velocity increased the power output, the corresponding efficiency was lower than that obtained at a water velocity of 0.80 m/s. The table below summarizes the recommended configurations for the two main design objectives.

| Design objective | Recommended configuration | Result |
|---|---|---|
| Highest efficiency | 60 mm cylinder diameter, 30-40 mm oscilation amplitude, 0.80 m/s water velocity | efficiency around 8.5% |
| Highest power output | 60 mm cylinder diameter, 40 mm oscilation amplitude, 1.20 m/s water velocity | Power output of 0.46 W |

#### Cylinder size comparison

The table below summarizes the performance of the three tested cylinder diameters. The comparison shows that the 60 mm cylinder provided the best overall performance, while the 50 mm and 70 mm cylinders produced lower average power and efficiency under the tested conditions.

| Cylinder | Performance Assessment |
|---|---|
| **50 mm** | The 50 mm cylinder produced moderate power and efficiency. Its highest efficiency was measured at 0.80 m/s water velocity, while the generated power at 1.20 m/s water velocity. Overall, its average performance was lower than that of the 60 mm cylinder. |
| **60 mm** | The 60 mm cylinder gave the best overall results. It had the highest average oscillation frequency, power and efficiency. The highest efficiency was measured at 0.80 m/s water velocity with a 30-40 mm amplitude, while the highest power was measured at 1.20 m/s water velocity. |
| **70 mm** | The 70 mm cylinder had a lower average oscillation frequency and efficiency than the 60 mm cylinder. Its highest efficiency was measured at 0.90 m/s water velocity. Continuous oscillation could not be maintained at some operating points. |

The measurements show that increasing the cylinder diameter does not automatically improve H-HOPE harvester performance.

A larger cylinder is exposed to a larger hydrodynamic force, but the final oscillation also depends on cylinder mass, natural frequency, spring stiffness, mechanical tuning and generator load. For the tested H-HOPE harvester configuration, **the 60 mm** cylinder provided the best power and efficiency results.

#### Effect of water velocity

Water velocity had a strong influence on the operation of the H-HOPE harvester.

At a water velocity below 0.70 m/s, the oscillation frequency and generated power were generally the lowest, which can be attributed to the lower kinetic energy available from the water flow. At water velocity of 0.80 m/s, the 50 and 60 mm cylinders achieved their highest efficiencies, indicating favorable conditions for converting the vortex-induced oscillations into electrical power. Results indicate that water velocities between 0.80 and 0.90 m/s provided the most favorable conditions for the H-HOPE harvester operation. At water velocity of 1.10 m/s, the oscillation frequency, generated power, and efficiency decreased for all three cylinders, suggesting a less favorable operating point for the H-HOPE harvester. At water velocity of 1.20 m/s, the oscillation frequency and generated power increased again, resulting in the highest absolute power output measured during the measurements; however, the efficiency remained lower than at water velocity of 0.80 m/s. 

Overall, the results show that increasing water velocity does not necessarily lead to higher efficiency of the H-HOPE harvester, as its performance also depends on the interaction between the vortex-shedding frequency and the dynamic characteristics of the system.

The measurements show that **water velocity has a larger effect on oscillation frequency, generated power and efficiency than the selected oscillation amplitude**.

### Practical build recommendation

Based on the water-channel measurements, the following configuration is recommended for H-HOPE harvester operation:

- use a **60 mm diameter cylinder**;
- use an **oscillation amplitude between 30 and 40 mm**; and
- aim for a water velocity of approximately **0.80 m/s**.

This configuration gave the best combination of efficiency and stable operation during testing.

If the main goal is to obtain the highest possible generated power, a water velocity of **1.20 m/s** can be used. The generated power is higher at this water velocity, but the efficiency is lower.

---

<div align="center">

</div>

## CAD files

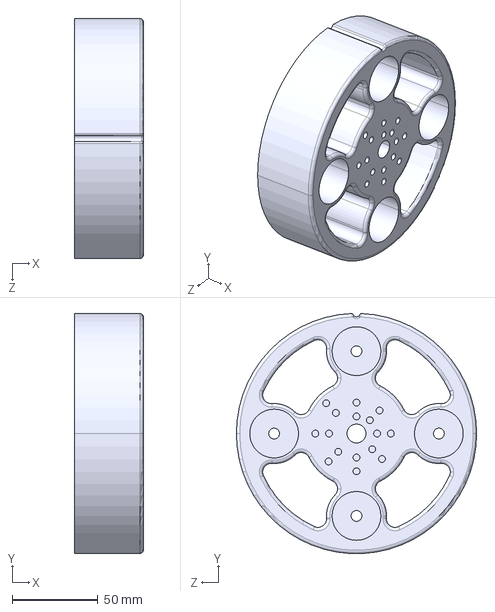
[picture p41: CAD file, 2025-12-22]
3D parts/STEP/Flywheel_right.STEP
40.0 x 139.8 x 140.0 mm

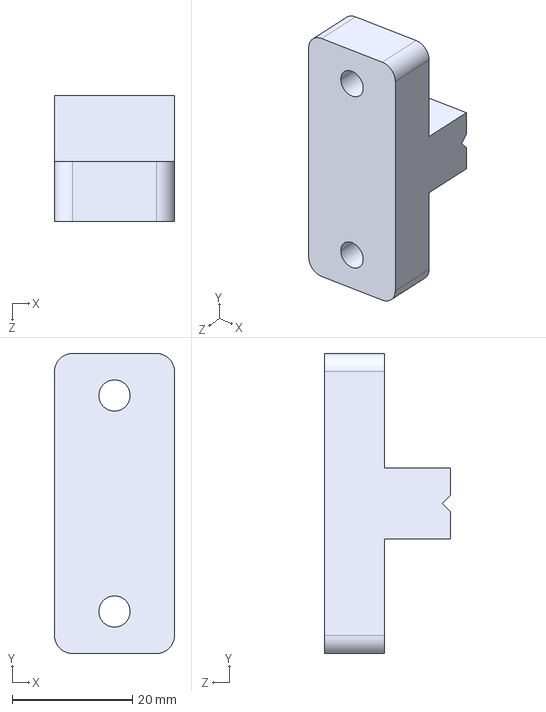
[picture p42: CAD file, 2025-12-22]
3D parts/STEP/Spring_holder_1.STEP
20.0 x 50.0 x 21.0 mm

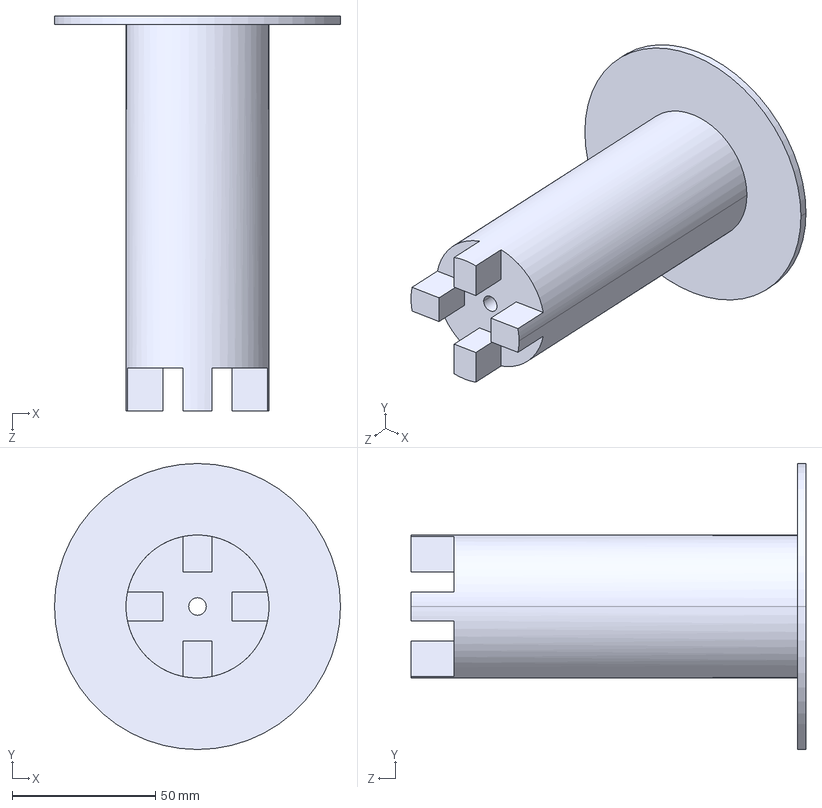
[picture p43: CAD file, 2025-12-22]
3D parts/STEP/49mm_cylinder_left.STEP
100.0 x 100.0 x 138.0 mm

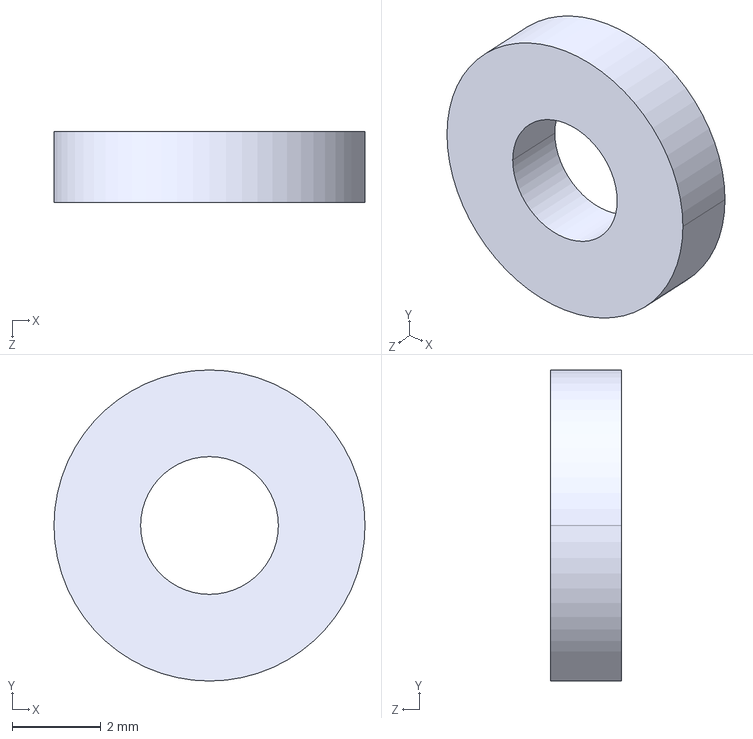
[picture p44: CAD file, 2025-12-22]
3D parts/STEP/Spacer_flywheel.STEP
7.00 x 7.00 x 1.60 mm

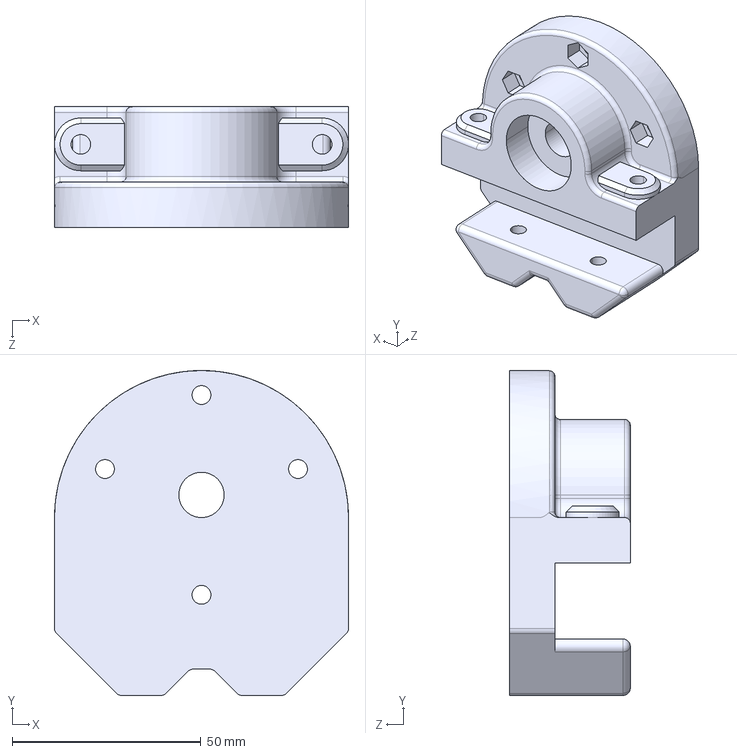
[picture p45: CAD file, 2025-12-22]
3D parts/STEP/Bearing_housing_and_generator_mount.STEP
78.0 x 86.2 x 32.0 mm

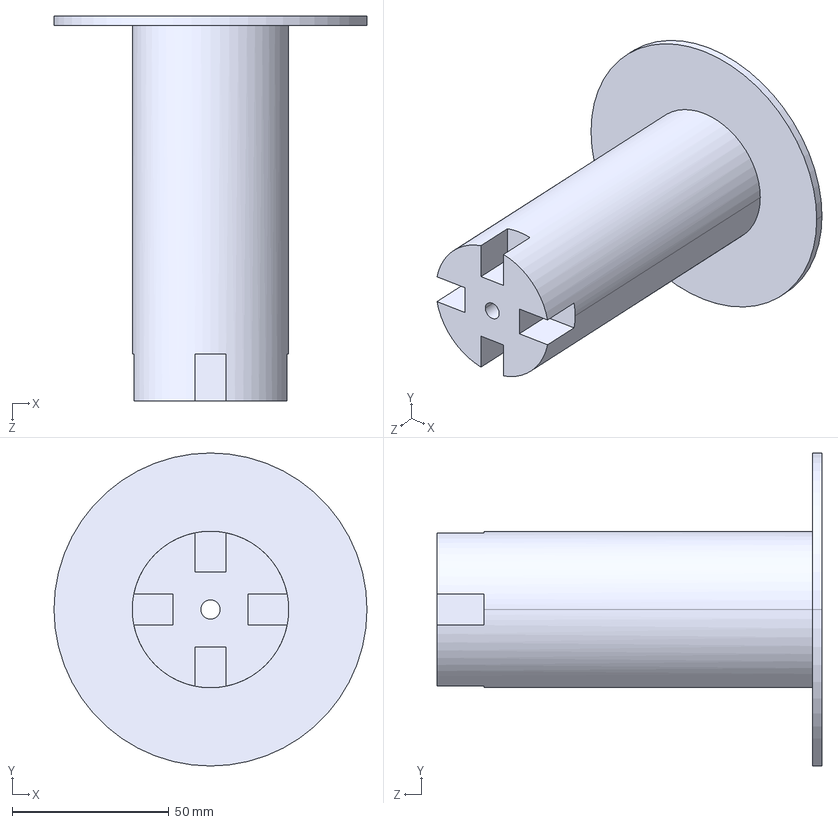
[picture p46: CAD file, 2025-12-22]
3D parts/STEP/49mm_cylinder_right.STEP
100.0 x 100.0 x 123.0 mm

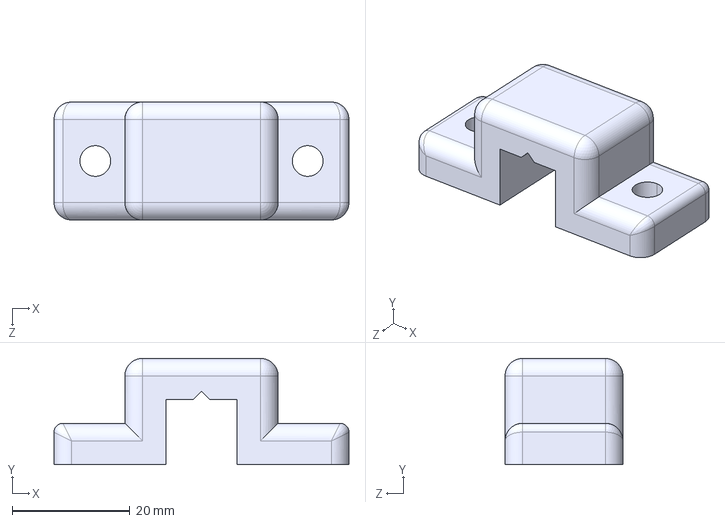
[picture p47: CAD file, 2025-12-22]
3D parts/STEP/Spring_holder_2.STEP
50.0 x 18.0 x 20.0 mm

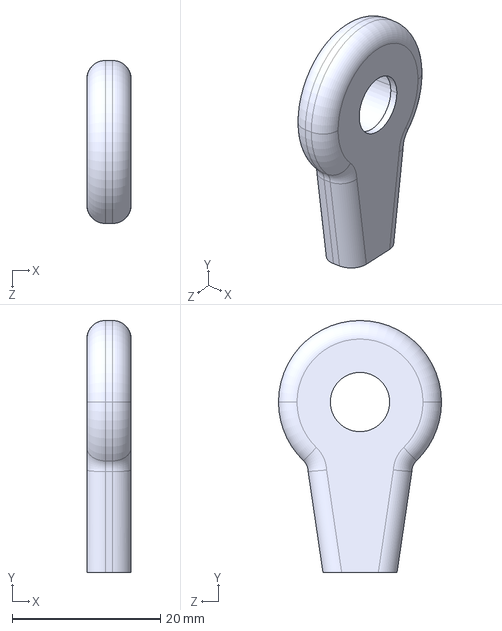
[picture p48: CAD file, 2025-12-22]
3D parts/STEP/Connecting_rod_holder.STEP
6.00 x 34.0 x 22.0 mm

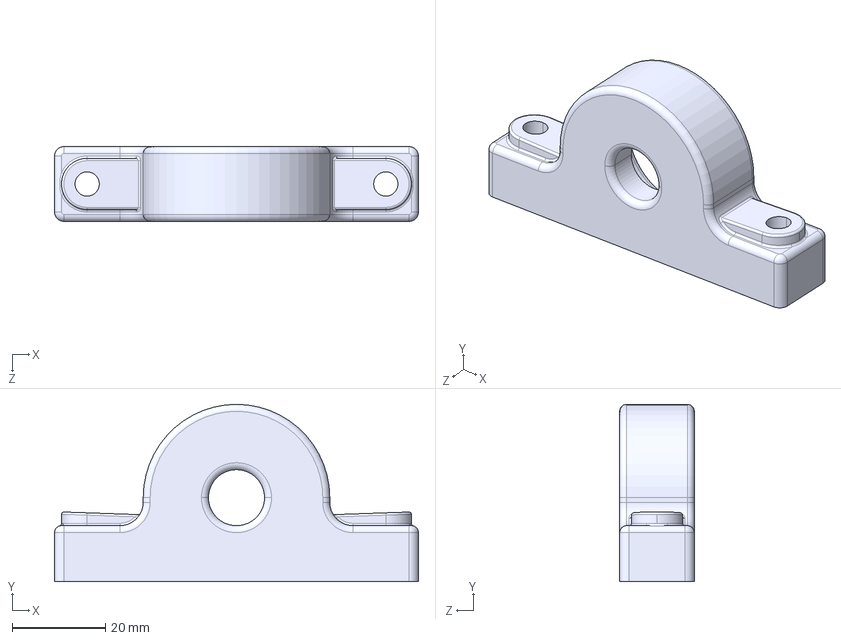
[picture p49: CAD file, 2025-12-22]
3D parts/STEP/Bearing_housing.STEP
78.0 x 38.0 x 16.0 mm

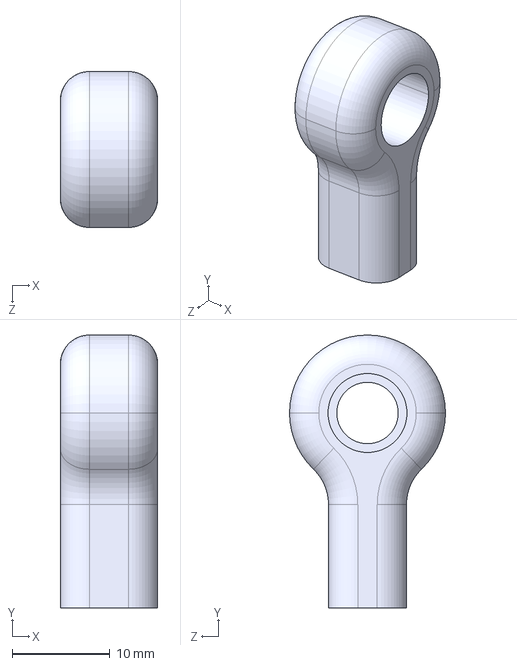
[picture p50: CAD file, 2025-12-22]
3D parts/STEP/Spring_holder_at_cylinder.STEP
10.0 x 28.0 x 16.0 mm

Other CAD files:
3D parts/STEP/Flywheel_left.STEP
3D parts/STL/49mm_cylinder_left.STL
3D parts/STL/49mm_cylinder_right.STL
3D parts/STL/Bearing_housing.STL
3D parts/STL/Bearing_housing_and_generator_mount.STL
3D parts/STL/Connecting_rod_holder.STL
3D parts/STL/Flywheel_left.STL
3D parts/STL/Flywheel_right.STL
3D parts/STL/Spacer_flywheel.STL
3D parts/STL/Spring_holder_1.STL
3D parts/STL/Spring_holder_2.STL
3D parts/STL/Spring_holder_at_cylinder.STL

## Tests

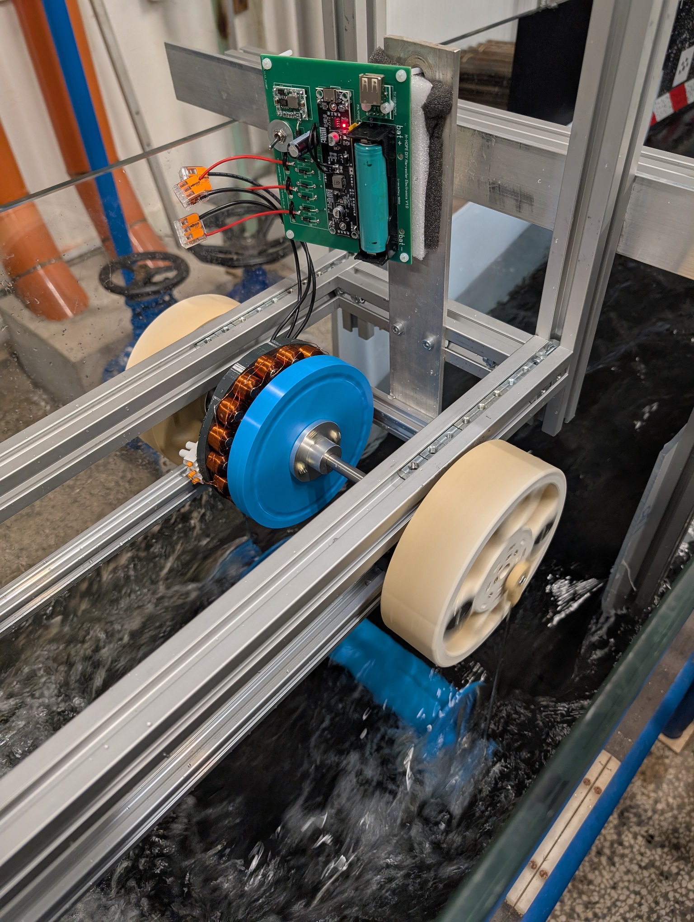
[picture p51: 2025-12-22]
images/Assembly/Harvester_test_1.jpg
